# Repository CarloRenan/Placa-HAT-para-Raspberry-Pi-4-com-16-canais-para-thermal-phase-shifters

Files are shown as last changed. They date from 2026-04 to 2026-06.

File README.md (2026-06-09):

# Placa-HAT-para-Raspberry-Pi-4-com-16-canais-para-thermal-phase-shifters

# Raspberry Pi 4 Photonic HAT Controller

Este repositório contém a documentação, esquemáticos e o software de controle para um HAT customizado de sinais mistos projetado para a Raspberry Pi 4. O sistema é focado no acionamento de matrizes fotônicas e condicionamento de sinais analógicos de alta precisão.

## 🧠 Arquitetura de Hardware

A rede de distribuição de energia e controle foi rigorosamente dimensionada para garantir integridade de sinal:
* **Conversão de Energia Principal:** Utiliza o conversor buck síncrono AP63205WU-7, reduzindo a tensão de entrada para um barramento regulado de 5V com capacidade de 2A.
* **Regulação Secundária (LDO):** Um AP2112K-3.3TRG1 fornece uma rede isolada de 3,3V dedicada aos circuitos digitais e analógicos sensíveis.
* **Conversão Digital-Analógica (DAC):** Implementada através do AD5391 (matriz multicanal), orquestrando a geração precisa dos sinais a partir da rede filtrada de 3,3V.
* **Condicionamento Analógico:** Matriz em cascata utilizando 4 CIs TLV2464 (totalizando 16 canais de amplificadores operacionais *rail-to-rail*), alimentados diretamente pelo barramento robusto de 5V.

## 💻 Software de Controle

Localizado na pasta `/src`, o script Python (`photonic_controller.py`) estabelece uma abstração sistêmica da placa. 
* Comunicação em altíssima velocidade (15 MHz) via barramento SPI dedicado (SPI0) para o DAC AD5391.
* Monitoramento autônomo via thread secundária para ler a transposição diferencial dos sensores INA180A2 (SPI1).
* Gatilhos emergenciais de contenção térmica via pinagem GPIO (Clear assíncrono).

## 📂 Estrutura do Repositório

* `/Projeto_DAC_Raspberry`: Arquivos fonte da PCB.
* `/docs`: Relatórios de viabilidade eletrotérmica e esquemáticos da placa.
* `/src`: Driver e interface de linha de comando em Python.



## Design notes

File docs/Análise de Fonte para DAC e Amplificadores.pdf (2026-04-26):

# Análise da tensão e corrente suficiente para alimentar o circuito

## Geração de Energia (Capacidade da Fonte)

- Conversor Buck (AP63205WU-7): Gera o barramento principal de 5 V. Suporta uma corrente máxima de saída de 2 A (2000 mA).
- Regulador LDO (AP2112K-3.3TRG1): Reduz os 5 V para gerar os barramentos de 3,3
V. Suporta uma corrente de saída máxima de 600 mA.

## Cálculo de Demanda do DAC (AD5391)

O DAC de 16 canais é alimentado em seus pinos analógicos e digitais pela tensão de 3,3 V proveniente do LDO.
- Corrente Analógica Máxima ($AI_{DD}$): 16 canais × 0,475 mA = 7,6 mA (com Boost ativado).
- Corrente Digital Máxima ($DI_{DD}$): O núcleo digital consome até 1,0 mA.
- Demanda Total do DAC (LDO 3,3 V): 7,6 mA + 1,0 mA = 8,6 mA.

## Cálculo de Demanda dos Amplificadores Operacionais (TLV2464)

A matriz de condicionamento utiliza 4 CIs TLV2464 (4 canais cada), totalizando 16 canais, alimentados diretamente pelo barramento de 5 V.
1. Demanda Quiescente (Base): 16 canais × 0,55 mA = 8,8 mA.
2. Demanda Máxima (Pior Caso/Curto-Circuito): 16 canais × 80 mA = 1280 mA.

## Demanda Global no Conversor Principal de 5 V

Todo o circuito (LDO + OPs) retira energia da via principal de 5 V.
- Cenário Base (Quiescente Total): 8,6 mA (DAC) + 8,8 mA (OPs) = 17,4 mA.
- Cenário Extremo (Pior Caso): 8,6 mA (DAC) + 1280 mA (OPs) = 1288,6 mA.
Como o conversor suporta até 2000 mA, a demanda máxima (1288,6 mA) representa aproximadamente 64% da capacidade total, garantindo uma margem de segurança adequada mesmo em situações de falha.

## Tabela Resumo de Consumo

Componente/Cálculo | Corrente Requerida | Limite da Fonte
DAC AD5391 (Via LDO 3.3V) | 8,6 mA | 600 mA (AP2112K)
Amp Op TLV2464 (Quiescente) | 8,8 mA | 2000 mA (AP63205)
Amp Op TLV2464 (Curto-circuito) | 1280 mA | 2000 mA (AP63205)
Consumo Global (Estado Passivo) | 17,4 mA | 2000 mA (AP63205)
Consumo Global (Pior Cenário) | 1288,6 mA | 2000 mA (AP63205)

## 1. Fundamentos da Arquitetura de Potência e Diretrizes de Sinal Misto

O projeto de arquiteturas de hardware de sinal misto de alta precisão e densidade exige um escrutínio rigoroso da rede de distribuição de energia. A tese central deste relatório analítico concentra-se em avaliar detalhadamente se a topologia de conversão de energia designada possui as características elétricas — especificamente os parâmetros de regulação de tensão e a capacidade máxima de fornecimento de corrente — para alimentar adequadamente uma matriz multicanal de conversores digital-analógico (DAC) em cascata com amplificadores operacionais de saída rail-to-rail. A questão central a ser respondida é se o conversor buck primário fornece tensão e corrente suficientes para o correto funcionamento do DAC e dos amplificadores operacionais documentados nos esquemáticos do projeto.

O sistema em questão depende do conversor buck síncrono AP63205WU-7 como o estágio primário de geração de energia, reduzindo a tensão de um barramento de entrada não regulado para um plano regulado de 5 V.

1 A partir deste barramento principal, a energia é distribuída em duas frentes distintas. Primeiro, o plano de 5 V alimenta diretamente uma matriz de amplificadores operacionais TLV2464, que são utilizados para o condicionamento e a entrega de potência analógica para as cargas externas.

3 Em segundo lugar, a tensão de 5 V atua como entrada para um regulador linear de baixa queda de tensão (LDO) AP2112K-3.3TRG1, cuja função é reduzir essa tensão para gerar barramentos isolados de 3,3 V.

4 Estes barramentos de 3,3 V são dedicados à alimentação do conversor digital-analógico AD5391, que orquestra a geração de precisão dos sinais analógicos a serem posteriormente buferizados pelos amplificadores.

3

Para fornecer uma resposta definitiva sobre a viabilidade e robustez do conversor buck primário em sustentar as cargas analógicas e digitais em cascata, é necessário conduzir uma análise eletrotérmica e elétrica multidisciplinar. As seções seguintes deste documento desconstruirão as capacidades operacionais do conversor AP63205WU-7, avaliarão os gargalos de dissipação de energia no LDO AP2112K, calcularão os orçamentos de corrente estática e dinâmica para o DAC AD5391 e para a matriz de amplificadores TLV2464, e abordarão fenômenos de integridade de energia de segunda ordem, como propagação de ruído de comutação, sequenciamento de alimentação e resposta a transientes de carga.

## 2. Geração de Potência Primária: O Conversor Buck Síncrono AP63205WU-7

O estágio de entrada de energia dita a estabilidade de todos os subsistemas a jusante. A topologia de conversão principal é construída em torno do AP63205WU-7, um regulador de tensão chaveado síncrono (buck) altamente integrado, encapsulado em um invólucro TSOT-26 de dimensões reduzidas.

1

### 2.1 Topologia Arquitetural e Características de Comutação

A arquitetura do AP63205WU-7 é definida por sua capacidade de aceitar uma ampla faixa de tensão de entrada, operando nominalmente desde 3,8 V até um limite máximo de 32 V.

1 Esta amplitude confere ao circuito uma enorme flexibilidade, permitindo que o sistema seja alimentado por barramentos industriais de 12 V ou 24 V, ou até mesmo baterias automotivas, mantendo a estabilidade na geração de uma saída fixa de 5 V.

6

O dispositivo é caracterizado pela integração monolítica de ambos os transistores de efeito de campo (MOSFETs) de potência no próprio substrato de silício. O MOSFET de alta

(high-side) apresenta uma resistência de condução (estado ligado ou | ) de 125
m$\Omega$, enquanto o MOSFET síncrono de baixa (low-side) utiliza uma topologia otimizada
com um | de apenas 68 m$\Omega$.

1 A retificação síncrona inerente ao AP63205 elimina a necessidade de um diodo Schottky de roda livre externo, o que melhora significativamente a eficiência volumétrica da placa de circuito impresso (PCI) e reduz drasticamente as perdas de comutação e condução.

Para um conversor buck operando no modo de condução contínua (CCM), as perdas de

condução em regime estacionário ( | ) dentro do invólucro podem ser matematicamente
aproximadas pelo ciclo de trabalho (duty cycle, | ) e pelas resistências térmicas dos
interruptores internos. O ciclo de trabalho é primariamente uma função da razão entre a tensão
de saída e a tensão de entrada ( | ). Assumindo um cenário de operação com

uma entrada nominal de 12 V para produzir a saída de 5 V, o ciclo de trabalho é de aproximadamente 41,6%.

A especificação mais crítica para a validação deste projeto é que o conversor AP63205WU-7 é classificado para fornecer uma corrente de saída contínua máxima de 2 A.

1
Operando em sua corrente máxima de 2 A, as perdas de condução estritas nos MOSFETs internos resultariam em menos de 400 mW de dissipação de calor. Esta alta eficiência térmica permite que o dispositivo TSOT-26 suporte a carga de 2 A de maneira sustentável, desde que as condições da placa e a temperatura ambiente não ultrapassem o limite operacional extremo de 85 °C e a temperatura máxima de junção de 160 °C.

2

### 2.2 Malha de Controle e Mitigação de Interferência Eletromagnética

A qualidade da energia fornecida a circuitos de sinal misto, como o DAC AD5391 e os amplificadores operacionais TLV2464, é tão importante quanto a quantidade de corrente disponível. A malha de controle do AP63205WU-7 emprega o modo de controle de corrente de pico (Peak Current Mode Control), acoplado a uma rede de compensação integrada internamente.

1 O controle de modo de corrente de pico fornece limitação de corrente ciclo a ciclo inerente e excelente resposta a transientes de linha, o que é altamente benéfico quando se alimentam CIs analógicos sensíveis a ruídos. A compensação interna minimiza a contagem de componentes passivos externos, acelerando a estabilização da malha durante transientes de carga abruptos — como aqueles encontrados quando uma matriz multicanal de amplificadores operacionais impulsiona subitamente cargas capacitivas ou resistivas.

A frequência de comutação do AP63205WU-7 é fixada em 1,1 MHz.

2 Operar em uma
frequência superior a 1 MHz permite a utilização de indutores de baixo perfil e capacitores cerâmicos de saída com baixa resistência em série equivalente (ESR), o que suprime efetivamente a ondulação (ripple) da tensão de saída. A análise esquemática indica a presença
de um indutor de 4,7 | H associado a dois capacitores de saída de 22 | F em paralelo, uma
configuração clássica para minimizar o ripple de tensão em conversores de 1,1 MHz.

Ainda mais relevante para aplicações analógicas é o fato de que o AP63205WU-7 integra uma função de Espalhamento de Espectro de Frequência (Frequency Spread Spectrum

- FSS) que introduz um jitter deliberado de | 6% na frequência de comutação.
| | 1 Ao modular
continuamente a frequência fundamental de comutação entre aproximadamente 1,034 MHz e 1,166 MHz, a energia eletromagnética emitida é impedida de se concentrar em uma única ressonância fundamental. Esta capacidade de FSS reduz drasticamente os picos de interferência eletromagnética (EMI), diminuindo a probabilidade de que emissões irradiadas ou conduzidas se acoplem às entradas de alta impedância dos amplificadores operacionais TLV2464 ou aos pinos de referência de precisão do DAC AD5391.

### 2.3 Estado Operacional Quiescente e Eficiência Dinâmica

Sob condições de ausência de carga (no-load), o AP63205 exibe uma corrente

quiescente ( | ) ultrabaixa de apenas 22 | A.

1 Embora a corrente quiescente seja uma métrica crucial para arquiteturas operadas por bateria, em sistemas industriais de alta densidade que impulsionam buffers analógicos contínuos, o carregamento dinâmico dominará inteiramente os cálculos de potência. A capacidade central do regulador de fornecer 5 V e sustentar picos de 2 A forma a base sólida a partir da qual as cargas subsequentes extrairão energia.

## 3. Regulação Secundária de Tensão: O LDO AP2112K-3.3TRG1

Embora o trilho de 5 V gerado pelo conversor buck primário forneça a potência maciça para o estágio de amplificação, componentes digitais e de sinal misto de menor geometria frequentemente exigem tensões operacionais menores. A análise do esquemático revela que o barramento de saída +5V_Ext alimenta um regulador linear AP2112K-3.3TRG1.

4 A função
deste componente é atuar como um estágio redutor linear (Low-Dropout - LDO) para gerar o plano de 3,3 V necessário para o conversor digital-analógico e para a interface de comunicação.

### 3.1 Queda de Tensão (Dropout) e Limites de Corrente

O AP2112K-3.3TRG1 é um regulador linear com saída fixa de 3,3 V e capacidade para fornecer uma corrente de saída contínua de até 600 mA.

4 O dispositivo opera com uma tensão de dropout (diferencial mínimo entre entrada e saída) típica de 250 mV, atingindo um pior cenário máximo de 400 mV quando operado na sua carga limite de 600 mA.

4

Como o conversor buck primário alimenta o LDO de forma contínua com uma tensão regulada de 5,0 V, o diferencial de tensão (headroom) através do LDO é de exatos 1,7 V (

). Este delta de 1,7 V é substancialmente mais alto que o limite de dropout de 400 mV estipulado pelo fabricante. Isso assegura categoricamente que o LDO jamais entrará na região de dropout ou sub-regulação, mantendo uma regulação de carga imaculada, especificada em 0,2 %/A, sob todas as condições transientes e de estado estacionário concebíveis nesta topologia.

9 A tensão de entrada nominal também está bem abaixo da tensão máxima absoluta suportada pelo AP2112K, que é de 6,0 V.

4

### 3.2 Análise de Gargalo Térmico e Dissipação do LDO

Embora as especificações elétricas do LDO permitam um fluxo de corrente de 600 mA

4
,
a física térmica de semicondutores impõe um limite muito mais restritivo ao AP2112K-3.3 quando este é operado a partir de uma fonte de 5 V. Em qualquer regulador linear, a potência

dissipada internamente ( ) é manifestada como calor e é igual ao produto da corrente de carga pelo diferencial de tensão entre a entrada e a saída:

Se o sistema de fato exigisse a corrente máxima nominal de 600 mA deste barramento de 3,3 V, a dissipação de energia interna no LDO seria de estratosféricos 1,02 Watts. O encapsulamento SOT-25 (também conhecido como SOT-23-5), em que este LDO é fornecido,

exibe uma resistência térmica entre a junção e o ambiente ( ) de 184 °C/W quando montado em uma placa de circuito impresso padrão sem dissipadores de calor dedicados de grande área.

11 Operar a 1,02 W de dissipação resultaria em um aumento fenomenal da temperatura de junção:

Somar esse aumento de temperatura a um ambiente industrial nominal de 25 °C

resultaria em uma temperatura de junção ( ) de 212 °C. Tal temperatura excede drasticamente a proteção de desligamento térmico incorporada no chip (Thermal Shutdown), que é ativada quando a junção atinge 160 °C

11 | , e também viola a temperatura de operação
máxima recomendada de 85 °C.

10

A conclusão fundamental da análise do regulador LDO é que, embora possua uma classificação elétrica de 600 mA, o gargalo térmico derivado da queda de 5 V para 3,3 V limita a corrente contínua sustentável a valores significativamente inferiores (idealmente abaixo de 200 mA para manter a integridade térmica de longo prazo). Felizmente, como será demonstrado na seção dedicada ao DAC AD5391, a corrente demandada pelo estágio de sinal misto em 3,3 V é de apenas uma fração desta capacidade, confirmando a robustez da escolha arquitetural sob condições reais de carga.

### 3.3 Rejeição de Ruído e Filtragem de Barramento Split

O AP2112K fornece uma Razão de Rejeição de Fonte de Alimentação (PSRR) de 65 dB na faixa de frequência de 100 Hz a 1 kHz, garantindo que ruídos de baixa frequência introduzidos na linha de 5 V sejam barrados da saída de 3,3 V.

| 4 No entanto, a eficiência de
rejeição decai em frequências mais altas. Para combater a interferência de alta frequência residual (como o ripple de 1,1 MHz proveniente do conversor buck), a análise esquemática revela um refinamento de projeto notável: a divisão do plano de 3,3 V.

O LDO gera a rede primária +3.3V_Ext, que é encarregada de alimentar as porções digitais barulhentas do circuito (como o núcleo digital do DAC). A partir desta rede, um filtro do tipo passa-baixa, composto por um indutor bead de ferrite (FB1, especificado como BLM18KG601SN1D) e capacitores de desvio cerâmicos, é implementado para gerar a rede +3.3V_Analog. Esta rede +3.3V_Analog isolada galvanicamente e filtrada de ruídos de alta frequência é então empregada para alimentar a matriz analógica de alta precisão do DAC, atestando o alto rigor aplicado na busca pela integridade do sinal misto.

## 4. Análise de Carga do Conversor Digital-Analógico: Família AD5391

Com as fundações da fonte de alimentação quantificadas e os comportamentos de tensão e térmicos delineados, o próximo passo na determinação da suficiência da corrente e tensão envolve a dissecção das cargas anexadas. A primeira carga substancial no fluxo de sinal é a matriz de conversores digital-analógico (DAC). O esquemático identifica a presença de um DAC de 16 canais. Os dados de pesquisa indicam que a família engloba o AD5390 (14 bits), AD5391 (12 bits) e AD5392 (8 canais, 14 bits).

3 A análise focará no AD5391 como referência para os modelos de 16 canais.

### 4.1 Identificação da Variante de Tensão Operacional

Os DACs desta família, particularmente o AD5391, são fisicamente divididos em duas subvariantes que ditam os requisitos operacionais de tensão de seu projeto interno: a versão

"-5", cujas especificações exigem um barramento de alimentação analógica ( | ) situado
entre 4,5 V e 5,5 V, e a versão "-3", projetada para operar em sistemas de baixa tensão com
um | compreendido entre 2,7 V e 3,6 V.

3 Em ambas as variantes, o pino de alimentação

do núcleo lógico e da interface digital ( ) aceita tensões numa ampla gama, estendendo-se desde 2,7 V até 5,5 V, garantindo a interoperabilidade com sistemas microcontroladores ou FPGAs independentemente das tensões do estágio analógico.

3

Uma interpretação errônea comum seria assumir que o DAC é alimentado diretamente pelo regulador buck principal de 5 V, o que exigiria a variante AD5391-5. No entanto, uma escrutinação atenta do diagrama esquemático fornecido refuta decisivamente essa suposição. Os pinos de alimentação analógica do DAC (AVDD 1 e AVDD 2) não estão conectados ao barramento +5V_Ext. Ao invés disso, eles são mapeados indubitavelmente para a rede filtrada +3.3V_Analog, proveniente do LDO AP2112K. Adicionalmente, a alimentação lógica do DAC, o pino DVDD, está conectado ao barramento digital limpo +3.3V_Ext, também proveniente do LDO.

Essa implementação baseada no LDO estabelece irrefutavelmente que a variante de dispositivo empregada ou necessária para esta placa é o AD5391-3 (ou as correspondentes

AD5390-3 / AD5392-3). Com os barramentos | e | ancorados ambos em 3,3 V, a
arquitetura da alimentação atende de forma perfeita e centralizada à recomendação do fabricante para o AD5391-3, cuja faixa operacional permitida de 2,7 V a 3,6 V engloba o valor de 3,3 V com ampla margem de segurança contra flutuações, respondendo positivamente à questão de que a tensão disponibilizada é suficiente e adequada.
| | 3

### 4.2 Restrições de Sequenciamento de Inicialização (Power-On Reset)

Projetar sistemas de sinal misto vai além do simples cálculo de correntes; as dinâmicas de tempo são cruciais para prevenir travamentos catastróficos em nível de silício (latch-up). A documentação técnica do AD5391 estipula um protocolo severo e compulsório relativo ao

sequenciamento da aplicação das tensões de alimentação nos pinos | e | . Para
assegurar a operação correta do circuito de reinicialização por ligação (Power-On Reset - POR)
e evitar estados indeterminados, o projetista deve garantir que o | seja aplicado
simultaneamente com o | , ou que o | antecipe o surgimento do | .

3

Adicionalmente, se houver um atraso na subida de tensão, o | deve estabilizar-se em
até, no máximo, 10 milissegundos após o estabelecimento do | .

3 Se o suprimento
analógico subir antes do suprimento digital, ou ultrapassar substancialmente essa janela temporal de tolerância, a rede interna do DAC pode incorrer em polarização parasita através de diodos internos de proteção contra descarga eletrostática (ESD), acionando o indesejado fenômeno de SCR latch-up que eleva subitamente o consumo de corrente do dispositivo e inutiliza a operação digital do chip.

Na presente arquitetura, o uso inteligente da rede de 3,3 V demonstra robustez notável nesse

quesito. Ambos os pinos | e | derivam suas fontes originais de energia da mesma
saída fundamental do LDO AP2112K-3.3, e assim as subidas em suas respectivas redes (+3.3V_Analog e +3.3V_Ext) ocorrem de maneira harmonicamente atrelada. As diferenças temporais na taxa de subida de tensão entre eles são causadas meramente pelos atrasos intrínsecos impostos pela constante de tempo RC gerada pelo indutor bead de ferrite e pelos capacitores locais de desvio no plano analógico. Essa modulação temporal parasitária reside tipicamente na ordem de dezenas a centenas de microssegundos, o que é inteiramente compatível e inofensivo sob a janela limitante rigorosa de 10 ms definida pelo fabricante.

3 Este
aspecto sela a viabilidade da topologia.

### 4.3 Orçamento Computacional do Consumo Quiescente e Dinâmico do DAC

A quantificação final acerca do consumo se concentra nas demandas elétricas de núcleo e acionamento estático. O consumo intrínseco de corrente deste DAC construído em processo semicondutor CMOS é minúsculo, mas ainda assim vital para agregar ao orçamento da fonte buck primaria, haja vista que toda a energia do LDO se origina do buck de 5 V.

A drenagem de corrente analógica contínua absorvida pelo pino | (definida como

) na variante -3 obedece à parametrização do registrador de controle interno que modula o recurso de ganho de resposta dinâmica (Slew Rate Boost).

3 A arquitetura dos
amplificadores de buffer de tensão de saída no chip é otimizada para o balanceamento entre velocidade e consumo.

- Sem o Impulso Dinâmico (Boost Mode Off): Por padrão após a inicialização, a malha aceleradora está desativada, configurando o tempo de assentamento (settling time) para
cerca de 8 | s e o slew rate típico em 1,5 V/ s. Nesse regime de economia, o consumo
nominal | por canal repousa em aproximadamente 0,25 mA, com um máximo
estatístico tolerável listado em 0,375 mA sob extremas variações de temperatura industrial (-40 °C a 85 °C).

3
- Com o Impulso Dinâmico (Boost Mode On): Quando um controle de sistema de mais alta velocidade exige transições abruptas, a configuração do registrador CR11 ativa o Boost Mode.

3 Este modo otimiza as correntes de polarização e aumenta o slew rate dos

canais para cerca de 2,5 V/ s. Em troca deste incremento performático, o teto da

corrente consumida | é impelido a um máximo de 0,475 mA por canal.

3

Para propósitos de assegurar as margens estruturais do regulador de tensão, o pior cenário (Boost Mode On operando a alta temperatura com todos os canais acionados) deve ser projetado. Com 16 canais ativos de maneira simultânea e absorvendo 0,475 mA de corrente do

de 3,3 V, a demanda global do núcleo analógico do chip ( | ) cristaliza-se
em:
O núcleo digital e as portas lógicas da interface SPI absorvem corrente adicional ( | ) por
meio do pino | . Quando a interface de comunicação é operada com sinais estáticos ou
em baixas frequências transicionais, a corrente | é insignificante. No entanto, quando
sujeita à comutação de alta velocidade (até o limite nominal especificado e assumindo
transições com níveis corretos em pinos CMOS), a corrente | alcança o teto máximo de
1,0 mA.

3

Integrando ambos os parâmetros computados ( | mais | ), conclui-se que o
requisito máximo teórico contínuo imposto por toda a operação do bloco DAC de 16 canais resume-se a escassos 8,6 mA. A capacidade do LDO AP2112K é de 600 mA.

4 Portanto, a
carga imposta pelo DAC perfaz uma fração microscópica (menos de 1,5%) da capacidade disponível em corrente secundária, corroborando de maneira explícita que as especificações estão mais do que supridas para este dispositivo em tela. Além do consumo intrínseco, os
saídas do DAC ( | a | ) não direcionam cargas resistivas de baixa impedância
significativas, pois seus sinais penetram diretamente na entrada não-inversora de altíssima impedância de porta dos amplificadores operacionais TLV2464 dispostos no estágio vizinho.

5. | Exigências | Eletrotérmicas | da | Matriz | de

## Amplificadores Operacionais: Família TLV2464

Conectados em topologia de cascata subsequente aos canais do DAC, os sinais analógicos necessitam ser submetidos a buffer, ganhos e condicionamento capaz de prover força motriz de corrente para as eventuais redes externas ao produto final. A arquitetura emprega a matriz do TLV2464, um pacote cuádruplo contendo amplificadores operacionais otimizados para baixo consumo de energia, exibindo um regime irrestrito de excursão de sinal tanto nas entradas quanto nas saídas, coloquialmente denominado rail-to-rail.

| | | | 3

A representação esquemática atesta a necessidade de lidar com 16 vias paralelas. Deste modo, são demandados e implantados quatro chips integrados individuais TLV2464CDR (cada qual contendo 4 amplificadores independentes).

| | 3

### 5.1 Restrições e Adequações na Tensão de Alimentação

O TLV2464 e os membros remanescentes de sua respectiva família ostentam

compatibilidade e flexibilidade superiores em relação a tensões de alimentação ( ). Segundo o guia de seleção e as classificações recomendadas pelo fabricante de silício, a tensão singular de alimentação do circuito deve incidir sobre a faixa permitida de 2,7 V a 6,0 V.

| | | | | 3

Ao avaliar as interconexões mostradas, observa-se que os pinos de polarização de alimentação (VDD+) de toda a fileira de amplificadores TLV2464 estão umbilicalmente atados de forma sólida ao barramento original +5V_Ext, derivado com rigor sem intermediários da conversão gerada pelo regulador buck principal AP63205WU-7.

| | 3
- Verificação: Uma alimentação de 5,0 V não apenas satisfaz a janela preconizada (2,7 V -6,0 V), como também fornece um patamar otimizado de dinâmica e amplitude de sinal. Ao ser nutrido por 5 V, as habilidades de excursão de sinal (rail-to-rail) garantem que a saída

possuirá um nível alto ( ) de 4,8 V (mínimo de 4,7 V) quando operando sob fornecimento de carga razoável de 10 mA. Igualmente, no dreno de corrente sob a

mesma magnitude de 10 mA, o nível baixo garantido ( ) pode atingir um teto de no máximo 0,3 V (tipicamente 0,2 V).

3 Como o próprio AD5391 operando a 3,3 V enviará

apenas os limites contidos de sua variação ( | V), a amplitude máxima a ser
engolida pelas entradas não inversoras repousará perfeitamente dentro da aceitação linear em modo comum (Common-Mode Input Voltage Range) dos amplificadores

energizados em 5 V, os quais possuem o privilégio de rastrear perfeitamente do marco

V até a própria tensão do barramento ( de 5 V).

3 Esta particularidade sela incontestavelmente a questão técnica quanto à suficiência das margens de tensão.

### 5.2 Orçamento de Corrente Quiescente (Demanda Passiva)

A balança que mensura o desempenho do TLV2464 versus sua sede elétrica revela notável compromisso com a economia. Os atributos inerentes ao ganho e à velocidade desta topologia CMOS não sacrificam em demasia a eficiência. Com um respeitável Produto Ganho-Banda (GBW) estipulado em 6,4 MHz e um razoável tempo de assentamento associado

a uma variação de fase de tensão (Slew Rate) delineado em 1,6 V/ s, cada canal no encapsulamento puxa para seu sustento interno uma pequena corrente de suprimento passiva

( | ) listada em 550 | A sob todas as faixas de trabalho industrial (aumento pequeno
frente ao patamar base estrito de 500 | A aferido em condição de temperatura ambiente e sem
estresse contíguo de transientes).
| | 3

Para estimar a porção puramente quiescente de toda essa formidável matriz de condicionamento na placa, consolidamos os quatro encapsulamentos de 4 vias (perfazendo 16 componentes ativos):

O valor computado de 8,8 mA define a barreira mais baixa de escoamento energético em corrente contínua que passará compulsoriamente, dia a dia e minuto a minuto, pelos filtros do barramento de 5 V provido pelo conversor buck. Evidentemente, esta cifra pálida desaparece frente à pujante magnitude de 2.000 mA do equipamento formador da energia, certificando sobra absurda na capacidade estática.

### 5.3 O Teto Dinâmico, Imposição de Cargas Extremas e Limitações Físicas do Empacotamento

Diferentemente do comportamento dócil e estável do conversor de sinais DAC, cujos elétrons desvanecem imperceptivelmente em resistências elevadas no domínio mega e giga ohm, o cenário modifica-se sensivelmente nas vias terminais do equipamento de controle, representadas pelos TLV2464. Estes portais fazem a mediação dos sinais gerados digitalmente contra a realidade mecânica e tangível, traduzida por longas linhas de transceptores, cabos coaxiais pesados, cargas térmicas ou transdutores mecânicos complexos. A integridade da corroboração da viabilidade exige o conhecimento das correntes induzidas pela carga dinâmica, independentemente da taxa passiva estática.

De acordo com as averiguações em ficha técnica, o TLV2464 fornece alta capacidade motriz impulsionadora. Em episódios nos quais for compelido a agir sob demanda ou erro (curto-circuito ou similar), o componente está homologado a entregar até a expressiva corrente

de curto-circuito ( | ) de | 80 mA (sendo 50 mA testado rigidamente e garantido
estatisticamente e 80 mA na distribuição típica da engenharia, assumida aqui como limite extremo no sentido de esgotamento total para teste das fontes).

3

Por premissa avaliativa fundamental de estresse (stress-testing paper model), caso se imponha a situação limite onde a falha nos sistemas externos ou comandos erráticos cause que simultaneamente, inexoravelmente, todos os 16 canais interconectados na matriz da placa tentem despachar 80 mA continuamente para o exterior, a corrente absoluta forçada contra a fonte ascenderia para:

Com base no pilar mestre das especificações prementes de fonte documentadas na seção 2.1

1
, as provisões estabelecem o limitante contínuo em 2,0 A. Dessa maneira, mesmo neste flagrante e colossal absurdo estressor imaginário de 1,28 Amperes dreno por parte dos estágios de saída, a capacidade vital de 2,0 Amperes do equipamento fonte AP63205 suportaria o esforço contínuo da demanda, guardando ainda formidável reserva excedente em trono de 720 miliamperes para compensação de perdas parasitárias de cabos ou necessidades de surtos microscópicos residuais. Fica assim matematicamente exaurida e devidamente resolvida a inquirição primária elaborada pelo consulente de forma afirmativa: Sim, há corrente elétrica global abundante.

### 5.3.1 O Abismo Térmico e o Verdadeiro Limitante do Sistema

No entanto, o relato estrito das capacidades dos transistores do conversor principal de silício dissimula as restrições práticas encontradas nas cápsulas encapsuladoras de plástico. Um exame analítico eletrotérmico dos próprios circuitos integrados amplificadores é mandatório para compreender as limitações práticas operacionais que, antes de drenarem por completo o reservatório do conversor, ceifariam o desempenho do dispositivo.

Em um contexto operacional adverso, postulemos o canal do op-amp sendo constrangido a drenar 80 mA a partir dos limitados reservatórios internos para uma eventual falha limitadora posicionada de modo a requerer tensão pela metade. Com alimentação total de 5 V, as perdas localizadas inerentes resultantes dessa queda seriam equivalentes ao diferencial das tensões contra a passagem da corrente.

Assumindo queda abrupta de 2,5 V internamente aos domínios comutadores para sustentar os 80 mA, a potência em watts despejada apenas como aquecimento reativo (

) em único circuito somaria 200 mW. Dentro da embalagem unificadora TLV2464D, onde residem concomitantemente quatro vias de atuação, essa perda multiplicada perfazeria

estrepitosos 800 mW ( W).

A tabela explícita de "Classificação de Dissipação" (Dissipation Rating Table) associada ao empacotamento pequeno tipo contorno de montagem em superfície (D - Small Outline 14 Pinos), fornece as amarras ineludíveis para sobrevivência em silício: A resistência ao

transbordo térmico ( equivalente) foi laboratorialmente cimentada em pesados 122,6

°C/W.

3

A potência de 800 mW causaria gradiente na junção contra o invólucro ( ) calculado por:

Em cenário confortável e temperado de operação interior industrial fixada estritamente aos 25 °C, o aquecimento provocado internamente conduziria os dados microscópicos imediatamente à elevação nominal para 123 °C.

3 O datasheet aponta que a máxima qualificação da temperatura contínua no núcleo central da operação permitida sem cataclismos

de tempo e sem fadiga estrutural ( | máximo e variação | expandido) encerra-se
perigosamente e ironicamente também perto dos idênticos 125 °C.
| | 3 Qualquer desvio
rudimentar superior de aquecimento externo da cabine faria com que a junção entrasse em zona perigosa ou mortífera.

Assim, com incontestável evidência físico-térmica, provamos o grande paradoxo do dimensionamento de sinal misto para controle industrial: A limitação da extração elétrica final imposta ao cliente jamais repousará nas limitações de fornecimento impostas pelo regulador Buck síncrono de 5 V. Muito tempo antes de que os potentes MOSFETs do conversor AP63205 sequer suem ao extrair seus maciços 2 Amperes, as minúsculas pastilhas que acondicionam e embalam o silício retificado dos TLV2464 entrarão em picos sufocantes por superaquecimento derivado do atrito eletrotérmico caso se submetam as saídas contínuas a frações massivas da capacidade de carga teórica da fonte. O regulador é uma usina amplamente dimensionada; a contenção mora inteiramente em quão bem a engenharia de arrefecimento nos chips analógicos finais for disposta.

Para ajudar no diagnóstico, os projetistas frequentemente introduzem resistências extrínsecas no circuito impresso, limitadores que servem de alívio e contorno do problema.

Constata-se efetivamente na topologia da imagem que os caminhos de saída ( | ou Main
AMP OPx IN) antes de finalizarem nos soquetes de engate, sofrem intervenções intencionais. Fichas de policarbonato com coeficiente positivo sensível de aquecimento — no caso referenciado no diagrama esquemático como MF-PSMF010X-2, os chamados fusíveis PTC (Positive Temperature Coefficient) — e monitores de resistência de derivação paralela baseados em CIs dedicados ao sensoriamento apurado de vias, do naipe INA180A2, efetuam o controle perene das malhas.

3 Tais componentes, ao lado da barreira do LDO AP2112, apenas consagram os contornos periféricos, cujo consumo insignificante em correntes do porte dos micro-amperes desaparece por completo sob as sobras colossais do sistema geral de energia.

| | 4

## 6. Integração Final e Orçamento Global de Requisitos de Potência

Para sintetizar o conhecimento das longas corroborações das seções transcorridas e cimentar as avaliações numa premissa técnica e legível para consultas dos pares atuantes no projeto, a matriz consolidada de orçamentos se faz primordial.

As tabelas de apuração listam não apenas o estado de base ou nominal operacional (fase inativa), mas projetam o avanço sob as piores hipóteses prementes de estresse das vias. Os cenários se baseiam em consumos passivos nominais da fonte principal AP63205 e na regulação passiva do AP2112 LDO operando os consumos dinâmicos dos CIs. A matriz assume os dados mais restritivos listados nas análises anteriores e nos trechos das folhas de dados pesquisados, não subestimando nenhuma corrente.

A tabela ilustra de forma concisa e definitiva as compatibilidades entre a geração de 2 A imposta pelo AP63205 versus a compilação máxima de todos os agentes atrelados e pendurados elétrica e parasitariamente abaixo desta linha mestre principal.

Subsistema/Comp onente Avaliado | Corrente Estática Máxima (Standby) | Corrente Nominal Carga (10 mA / canal operando) | Limite Extremo Hipotético Máximo de Saída Curto (80 mA/ch)
Conversor Buck AP63205 (Inerente) | 0,022 mA | 0,022 mA | 0,022 mA
Regulador LDO AP2112K (Inerente) | 0,055 mA | 0,055 mA | 0,055 mA
Matriz DAC AD5391 (Rede ) | 7,600 mA | 7,600 mA | 7,600 mA
Matriz DAC AD5391 (Rede ) | 1,000 mA | 1,000 mA | 1,000 mA
Matriz de Amp Op TLV2464 (Base) | 8,800 mA | 8,800 mA | 8,800 mA
Total Corrente Imposta Via Saída | 0,000 mA | 160,000 mA | 1280,000 mA

(Cargas Amp Op)

Consumo Total Consolidado do Projeto | 17,477 mA | 177,477 mA | 1297,477 mA
Capacidade Disponível do Conversor 1 | 2000,00 mA | 2000,00 mA | 2000,00 mA
Margem Total de Energia Sobressalente Global | 99,1% Excedente | 91,1% Excedente | 35,1% Excedente

A evidência contida e agrupada prova estatisticamente, com a veracidade das contas matemáticas e as especificações de datasheet dispostas nas fontes indexadas, o preceito central submetido na questão geradora deste documento. A fonte formadora (regulador buck comutada contendo saída regulada de 5 V / capacidade retentiva de 2 A) suporta as cargas pendentes do DAC e da fileira de matriz dos Operacionais (OPs) de forma folgada.

Durante os percalços do trajeto da aplicação do cenário realista (condicionamento sob níveis normais de saídas até 10 mA em cargas limitadas e sob fusíveis limitadores PTC documentados no projeto original

3
), as folgas disponíveis na matriz indicam que o conversor comutador Buck passa por uma existência inteiramente plácida possuindo 91,1% de corrente bruta aguardando inutilizada. Nem sequer com o projeto encurralado na barreira final do desastre máximo contendo quase 1,3 A drenados — ponto onde antes as matrizes já teriam derretido as suas proteções por limite térmico como fartamente atestado na seção de avaliação física da pastilha empacotada D-14 — o sistema de energia se curvaria, exibindo fortes e incólumes 35% adicionais de robustez em potência livre.

1

## 7. Considerações Avançadas: Rejeição de Ruído e Integridade do Condicionamento Analógico

Garantir os elétrons e os diferenciais nominais em níveis de consumo mediano atinge apenas as premissas triviais para que os subsistemas "acordem". Num equipamento voltado à modulação apurada de redes e correntes — na exata via onde atuam DACs contendo taxas como 12 e 14 bits (AD5391/90) e malhas analógicas fechadas em OPs — impera adicionalmente que o sistema apresente limpeza inaudível e sem resíduos nos vetores do barramento gerador.

A natureza da comutação rápida empregada pelo síncrono AP63205WU-7 insere na rede artefatos que não existem com a aplicação singela das baterias ideais antigas. Com uma comutação assente a 1,1 MHz fixos (aprimorada em variabilidade de dispersão pela modulação de 6% FSS contra harmônicas)

1
, flutuações e dentes-de-serra residuais (ripple), usualmente na casa dos 10 mV a 30 mV, vagarão perenemente impulsionados pelo barramento de 5 V.

Quando o DAC, responsável e dependente da variação mínima, se encarrega da transcrição da codificação binária em voltagem escalar, a magnitude isolada do nível de transição elétrico menor mensurável do chip AD5391 (Least Significant Bit ou LSB),

configurado nas fontes documentadas nas especificações de precisão de LSB de 1 bit de

desvio

3
, equivale à proporção absoluta associada ao nível de tensão da rede dividida por para as versões comumente atreladas ao conversor de 12 bits. Se este artefato residual em 1,1 MHz de dezenas de milivolts viajar incólume no barramento primário de energia sem bloqueio
para as entradas | de sensibilidade contida, poderia embutir contaminações maciças do
erro, ofuscando a estabilidade real das resoluções no bloco.

3

Para aplacar esse cenário em conformidade aos limites dos chips, o comportamento do esquemático na conversão inicial e divisão (do isolado 3,3 V via matriz linear reguladora e filtros indutivos) se exibe brilhante. Os 30 mV ruidosos que viajam desde a geração perdem substancial resíduo na contenção gerada pelos laços limitadores dos divisores da rede AP2112K-3.3 que atua passiva sob índices típicos listados de cerca de 65 decibéis em PSRR para patamares sônicos (degradando em frequências maiores inerentemente pelas suas chaves).

4 A limpeza final efetiva para sanar e amansar a harmônica extrema no barramento

específico do | se faz não pelo LDO per se, mas pela notória blindagem propiciada nos
elos paralelos LC elaborada por FB1 e as malhas capacitivas cerâmicas na divisão +3.3V_Analog.

No campo de análise dos amplificadores sob o plano principal impuro de 5 V, em observação às propriedades de isolação internas intrínsecas construídas na malha analógica dos próprios CIs TLV2464 perante este barramento exposto, as especificações documentais asseguram resiliência maciça.

3 É estipulado formalmente pela literatura e guias fornecidos para esta matriz uma Taxa Racionalizada de Rejeição e Intervenção de Fonte de Alimentação (KSVR ou PSRR analógico interno do estágio) estancada num típico valor limiar massivo de 85 dB contra aberrações nos pinos propulsores.

3

Com base nisto, em conjunto com as garantias plenas da blindagem filtrada (ferrite e bypass na capacitância local) que constam associados a essas matrizes, o dimensionamento elétrico passa intacto e perfeitamente ajustado pela revisão da barreira da integridade do condicionamento.

## 8. Síntese Conclusiva

Por meio da profunda análise de requisitos eletrotérmicos, da dissecção funcional comparativa dos projetos em esquemas elétricos e das folgas paramétricas consolidadas na compilação exaustiva do projeto e nos recortes da literatura técnica validada (datasheets) e cruzada, as indagações acerca da viabilidade funcional são respondidas afirmativamente sem margem para ambiguidade conceitual de nível elétrico:

A fonte propulsora em regime síncrono Buck operada pelo comutador de redução passiva AP63205 garante a irrestrita entrega e modulação na suficiência para as tensões necessárias do projeto (produzindo o barramento forte em 5 V e fornecendo as bases perfeitas atreladas aos limites ideais estipulados entre 2,7 V e 6,0 V exigidos aos amplificadores). A energia também embasa impecavelmente a contenção auxiliar redutora via LDO restrita a 3,3 V requerida em virtude das versões específicas restritivas contidas em modelos com terminação "-3" da fileira dos AD5391.

No espectro de potência absoluta transferível (amperagem estática e transiente), a geração primária listada para limites em 2.000 miliamperes é formidavelmente hiperdimensionada frente aos meros ~177 miliamperes necessários e suficientes para compor o consumo operacional esperado e condicionado pelas redes em estado prático do ambiente das cargas das interfaces analógicas anexadas, confirmando na completude irrestrita o sucesso operacional desta topologia.

Referências citadas

3. AP63205WU-7 Switching Voltage Regulator: 5V 2A TSOT26, AP63205WU-7
Regulators | Datasheet | - | Utmel, | acessado | em | abril | 26, | 2026,
https://www.utmel.com/components/ap63205wu-7-switching-voltage-regulator-5v-2a-tsot26-ap63205wu-7-regulators-datasheet?id=1164 (https://www.utmel.com/components/ap63205wu-7-switching-voltage-regulator-5v-2a-tsot26-ap63205wu-7-regulators-datasheet?id=1164)
4. AP63205WU-7 Diodes Inc. - Voltage Regulators - Switching - Distributors, Price
Comparison, and Datasheets | Octopart component search, acessado em abril 26,
2026, https://octopart.com/part/diodes-inc/AP63205WU-7
5. AP2112K-3.3TRG1 Diodes Incorporated | Voltage Regulators - DigiKey, acessado
em | | abril | | 26, | | | | 2026,
https://www.digikey.com/en/products/detail/diodes-incorporated/AP2112K-3-3TRG1/4470746 (https://www.digikey.com/en/products/detail/diodes-incorporated/AP2112K-3-3TRG1/4470746)
6. AP2112K-3.3TRG1 | DIODES | Price | In Stock | LCSC Electronics, acessado em
abril 26, 2026, https://www.lcsc.com/product-detail/C51118.html
7. AP63205WU-7 Diodes Incorporated | Mouser, acessado em abril 26, 2026,
https://www.mouser.com/ProductDetail/Diodes-Incorporated/AP63205WU-7?qs=u 16ybLDytRZtkj8PzdWCOw%3D%3D (https://www.mouser.com/ProductDetail/Diodes-Incorporated/AP63205WU-7?qs=u16ybLDytRZtkj8PzdWCOw%3D%3D)
8. AP63205WU-7 Diodes Incorporated | Voltage Regulators - DigiKey, acessado em
abril | | | 26, | | | | | 2026,
https://www.digikey.com/en/products/detail/diodes-incorporated/AP63205WU-7/98 58424 (https://www.digikey.com/en/products/detail/diodes-incorporated/AP63205WU-7/9858424)
9. AP63205WU-7 Datasheet Diodes, Download PDF - RadioLocman, acessado em
abril | | | 26, | | | | | 2026,
https://www.radiolocman.com/datasheet/data.html?di=580813&/AP63205WU-7

10. AP2112K-3.3TRG1: 600mA LDO Voltage Regulator Review & Applications -
Utmel, | acessado | em | abril | 26, | 2026,
https://www.utmel.com/components/how-diodes-incorporated-ap2112k-3-3trg1-became-a-game-changer?id=4798 (https://www.utmel.com/components/how-diodes-incorporated-ap2112k-3-3trg1-became-a-game-changer?id=4798)
11. AP2112K-3.3TRG1 Diodes Incorporated - Mouser Electronics, acessado em abril
26, | | | | | 2026,
https://www.mouser.com/ProductDetail/Diodes-Incorporated/AP2112K-3.3TRG1?qs=x6A8l6qLYDDPYHosCdzh%2FA%3D%3D (https://www.mouser.com/ProductDetail/Diodes-Incorporated/AP2112K-3.3TRG1?qs=x6A8l6qLYDDPYHosCdzh/A%3D%3D)
12. AP2112 Description Features Applications Pin Assignments - Mouser Electronics,
acessado | em | abril | 26, | 2026,
https://www.mouser.com/datasheet/2/115/AP2112-271550.pdf

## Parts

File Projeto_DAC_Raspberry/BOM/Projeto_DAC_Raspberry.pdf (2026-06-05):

Line # | Name | Description | Designator | Revision ID | Revision State | Revision Status | Quantity | Manufacturer 1 | Manufacturer Part Number 1 | Manufacturer Lifecycle 1 | Supplier 1 | Supplier Part Number 1 | Supplier Unit Price 1 | Supplier Subtotal 1
| AD5391BSTZ-3 | 16 Channel 12-Bit Single-Supply Voltage Output Digital-to-Analog Converter with Serial Interface, 3 V, -40 to +85 degC, ST-52, Pb-Free, Tray | U2 | CMP-0318-00791-2 | Released | Up to date | | 1 Analog Devices | AD5391BSTZ-3 | Volume Production | Mouser | 584-AD5391BSTZ-3 | 60.29 | 60.29
| MF-PSMF010X-2 | PTC RESET FUSE 15V 100MA 0805 | F1, F2, F3, F4, F5, F6, F7, F8, F9, F10, F11, F12, F13, F14, F15, F16 | CMP-07400-000017-1 | New From Design | Up to date | 16 Bourns | | MF-PSMF010X-2 | Volume Production | DigiKey | MF-PSMF010X-2CT-ND | 0.29 | 4.64
| SMAJ5.0A | SMAJ Transient Voltage Suppressor Diode Series, 3.5 V, -55 to 150 degC, 2-Pin SMA, RoHS, Tape and Reel | D1, D2, D3, D4, D5, D6, D7, D8, D9, D10, D11, D12, D13, D14, D15, D16 | CMP-2000-07090-1 | Released | Up to date | 16 Bourns | | SMAJ5.0A | Volume Production | Mouser | 652-SMAJ5.0A | 0.261 | 4.18
| AP2112K-3.3TRG1 | IC REG LINEAR 3.3V 600MA SOT25 | U6 | CMP-12756-000035-1 | New From Design | Up to date | | 1 Diodes Inc. | AP2112K-3.3TRG1 | Volume Production | Mouser | 621-AP2112K-3.3TRG1 | 0.57 | 0.57
| AP63205WU-7 | IC REG BUCK 5V 2A TSOT23-6 | U7 | | Not managed | | | 1 Diodes Inc. | AP63205WU-7 | Volume Production | Mouser | 621-AP63205WU-7 | 1.75 | 1.75
| DMP4065S-7 | MOSFET P-CH 40V 2.4A SOT23 | T1 | CMP-12801-000050-1 | New From Design | Up to date | | 1 Diodes Inc. | DMP4065S-7 | Volume Production | Mouser | 621-DMP4065S-7 | 0.46 | 0.46
| LTST-C170GKT | LED GREEN CLEAR SMD | D19, D20 | CMP-1674-00002-6 | New From Design | Up to date | | 2 Diodes Inc. | LTST-C170GKT | Volume Production | Mouser | 859-LTST-C170GKT | 0.1 | 0.2
| SMBJ28CAQ-13-F | TVS DIODE 28VWM 45.4VC SMB | D17 | | Not managed | | | 1 Diodes Inc. | SMBJ28CAQ-13-F | Volume Production | Mouser | 621-SMBJ28CAQ-13-F | 0.27 | 0.27
| FH28-50S-0.5SH(05) | CONN FFC BOTTOM 50POS 0.50MM R/A | J1 | CMP-11609-000009-1 | New From Design | Up to date | | 1 HIROSE ELECTRIC | FH28-50S-0.5SH(05) | Volume Production | DigiKey | HFV150DKR-ND | 2.19 | 2.19
| SG73S1ETTP1R0J | | R1, R2, R3, R4, R5, R6, R7, R8, R9, R10, R11, R12, R13, R14, R15, R16 | CMP-2002-04124-1 | Released | Up to date | 16 KOA Speer | | SG73P1ETTP1R0J | Volume Production | Mouser | 660-SG73P1ETTP1R0J | 0.042 | 0.672
| MMSZ5245B-TP | DIODE ZENER 15V 500MW SOD123 | D18 | | Not managed | | | 1 MCC | MMSZ5245B-TP | Volume Production | DigiKey | MMSZ5245B-TPMSCT-ND | 0.14 | 0.14
| 1255AY-4R7M=P3 | FIXED IND 4.7UH 4A 23 MOHM SMD | L1 | | Not managed | | | 1 Murata | 1255AY-4R7M=P3 | Volume Production | DigiKey | 490-10812-1-ND | 0.39 | 0.39
| BLM18KG601SN1D | Chip Ferrite Bead, 0603, 600Ω @ 100MHz, 0.15Ω, 25%, 1.3A | FB1 | CMP-0686-00581-3 | Released | Up to date | | 1 Murata | BLM18KG601SN1D | Volume Production | Mouser | 81-BLM18KG601SN1D | 0.1 | 0.1
| GRM31CR60J476ME19L | Chip Multilayer Ceramic Capacitors for General Purpose, 1206, 47uF, X5R, 15%, 20%, 6.3V | C41, C47 | CMP-2000-06344-2 | New From Design | Up to date | | 2 Murata | GRM31CR60J476ME19L | Volume Production | Mouser | 81-GRM426X476M6.3L | 0.5 | | 1
| GRM188R61A106ME69J | Chip Multilayer Ceramic Capacitors for General Purpose, 0603, 10uF, X5R, 15%, 20%, 10V | C6, C7, C8 | CMP-06035-033844-1 | New From Design | Up to date | | 3 Murata | GRM188R61A106ME69J | Volume Production | Mouser | 81-GRM188R61A106ME9J | 0.13 | 0.39
| Resistor 10k +/-1% 0603 100 mW | Chip Resistor, 10 KOhm, +/- 1%, 01 W, -55 to 155 degC, 0603 (1608 Metric) | R21, R23, R24, R25, R29, R31, R32, R33, R37, R39, R40, R41, R45, R47, R48, R49 | | Not managed | | 16 Panasonic | | ERJPC3B1002V | Volume Production | Mouser | 667-ERJ-PC3B1002V | 0.147 | 2.35
| 5444262 | TERM BLOCK HDR 2POS 90DEG 3.81MM | J3 | | Not managed | | | 1 Phoenix Contact | 5444262 | Volume Production | DigiKey | 277-11313-ND | 0.39 | 0.39
| 5447861 | TERM BLOCK PLUG 2POS STR 3.81MM | J2 | | Not managed | | | 1 Phoenix Contact | 5447861 | Volume Production | Mouser | 651-5447861 | 1.14 | 1.14
| CL21A226MAYNNNE | CAP CER 22UF 25V X5R 0805 | C10, C11 | | Not managed | | | 2 Samsung Electro-Mechanics | CL21A226MAYNNNE | Volume Production | Mouser | 187-CL21A226MAYNNNE | 0.26 | 0.52
| CL31A106KBHNNNE | CAP CER 10UF 50V X5R 1206 | C12 | | Not managed | | | Samsung Electro-1 Mechanics | CL31A106KBHNNNE | Volume Production | Mouser | 187-CL31A106KBHNNNE | 0.36 | 0.36
| CRGCQ0805F100K | CRGCQ 0805 100K 1% | R19 | CMP-03211-000816-1 | New From Design | Up to date | | 1 TE Connectivity | CRGCQ0805F100K | Volume Production | DigiKey | A129773CT-ND | 0.1 | 0.1
| CRGCQ0805J470R | CRGCQ0805 470Ω 0.125W ±100ppm/ °C 5% 150V | R20 | CMP-03211-002267-1 | New From Design | Up to date | | 1 TE Connectivity | CRGCQ0805J470R | Volume Production | DigiKey | A130132CT-ND | 0.1 | 0.1
| SMA-A0207FTDT22R | SMA-A 0207 22Ω 1W 50ppm/ºC 1.00% 350V | R53 | CMP-03211-006581-1 | New From Design | Up to date | | 1 TE Connectivity | SMA-A0207FTDT22R | Volume Production | DigiKey | A0207FTDT22RCT-ND 1712-SMA- | 0.33 | 0.33
| INA180A2IDBVR | IC CURR SENSE 1 CIRCUIT SOT23-5 | U4, U5, U8, U9, U10, U11, U12, U13, U15, U16, U17, U18, U20, U21, U22, U23 | CMP-04895-000287-1 | New From Design | Up to date | 16 Texas Instruments | | INA180A2IDBVR | Volume Production | DigiKey | 296-47653-1-ND | 0.319 | 5.1
| TLV2464CDR | Quad Low Power, Rail-to-Rail Input / Output Operational Amplifier, 2.7 to 6 V, 0 to 70 degC, 14-pin SOIC (D14), Green (RoHS & no Sb/Br) | U1, U3, U14, U19 | CMP-0271-00006-3 | Released | Up to date | | 4 Texas Instruments | TLV2464CDR | Volume Production | DigiKey | 296-2436-1-ND | 3.44 | 13.76
| VJ0603Y104MXJCW1BC | | C2, C3, C4, C5, C9, C13, C14, C15, C16, C17, C18, C19, C20, C21, C22, C23, C24, C25, C26, C27, C28, C29, C30, C31, C32, C33, C34, C35, C36, C37, C38, C39, C40, C42, C43, C44, C45, C46 | CMP-2006-00058-1 | Released | Up to date | 38 Vishay | | VJ0603Y104MXJCW1BC | Volume Production | DigiKey | 720-VJ0603Y104MXJCW1BCCT-ND | 0.0438 | 2.19
| 61204021621 | WR-BHD Straight Male, Box Header, Through Hole, 2 Rows, 40 Contacts, 2.54mm Pitch | P1 | CMP-1502-00015-4 | Released | Up to date | | 1 Wurth Elektronik | 61204021621 | Volume Production | DigiKey | 732-5401-ND | 1.21 | 1.21
| C0805C104K5RACTU | CAP CER 0.1UF 50V X7R 0805 | C1 | CMP-2007-00279-2 | New From Design | Up to date | | 1 Yageo Group | C0805C104K5RACTU | Volume Production | DigiKey | 399-C0805C104K5RACTUDKR-ND | 0.13 | 0.13
| RC0805FR-071KL | Chip Resistor, 1 KOhm, +/- 1%, 125 mW, -55 to 155 degC, 0805 (2012 Metric), RoHS, Tape and Reel | R18 | CMP-2100-03671-1 | Released | Up to date | | 1 Yageo Group | RC0805FR-071KL | Volume Production | DigiKey | 311-1.00KCRDKR-ND | 0.1 | 0.1
| RC0805FR-071ML | RES 1M OHM 1% 1/ 8W 0805 | R17 | | Not managed | | | 1 Yageo Group | RC0805FR-071ML | Volume Production | DigiKey | 311-1.00MCRCT-ND | 0.1 | 0.1
| Resistor 1k +/-1% 0603 100 mW | Chip Resistor, 1 KOhm, +/-1%, 0.1 W, -55 to 155 degC, 0603 (1608 Metric) | R22, R26, R27, R28, R30, R34, R35, R36, R38, R42, R43, R44, R46, R50, R51, R52 | | Not managed | | 16 Yageo Group | | SR0603FR-07100KL | Volume Production | Mouser | 603-SR0603FR-07100KL | 0.078 | 1.25

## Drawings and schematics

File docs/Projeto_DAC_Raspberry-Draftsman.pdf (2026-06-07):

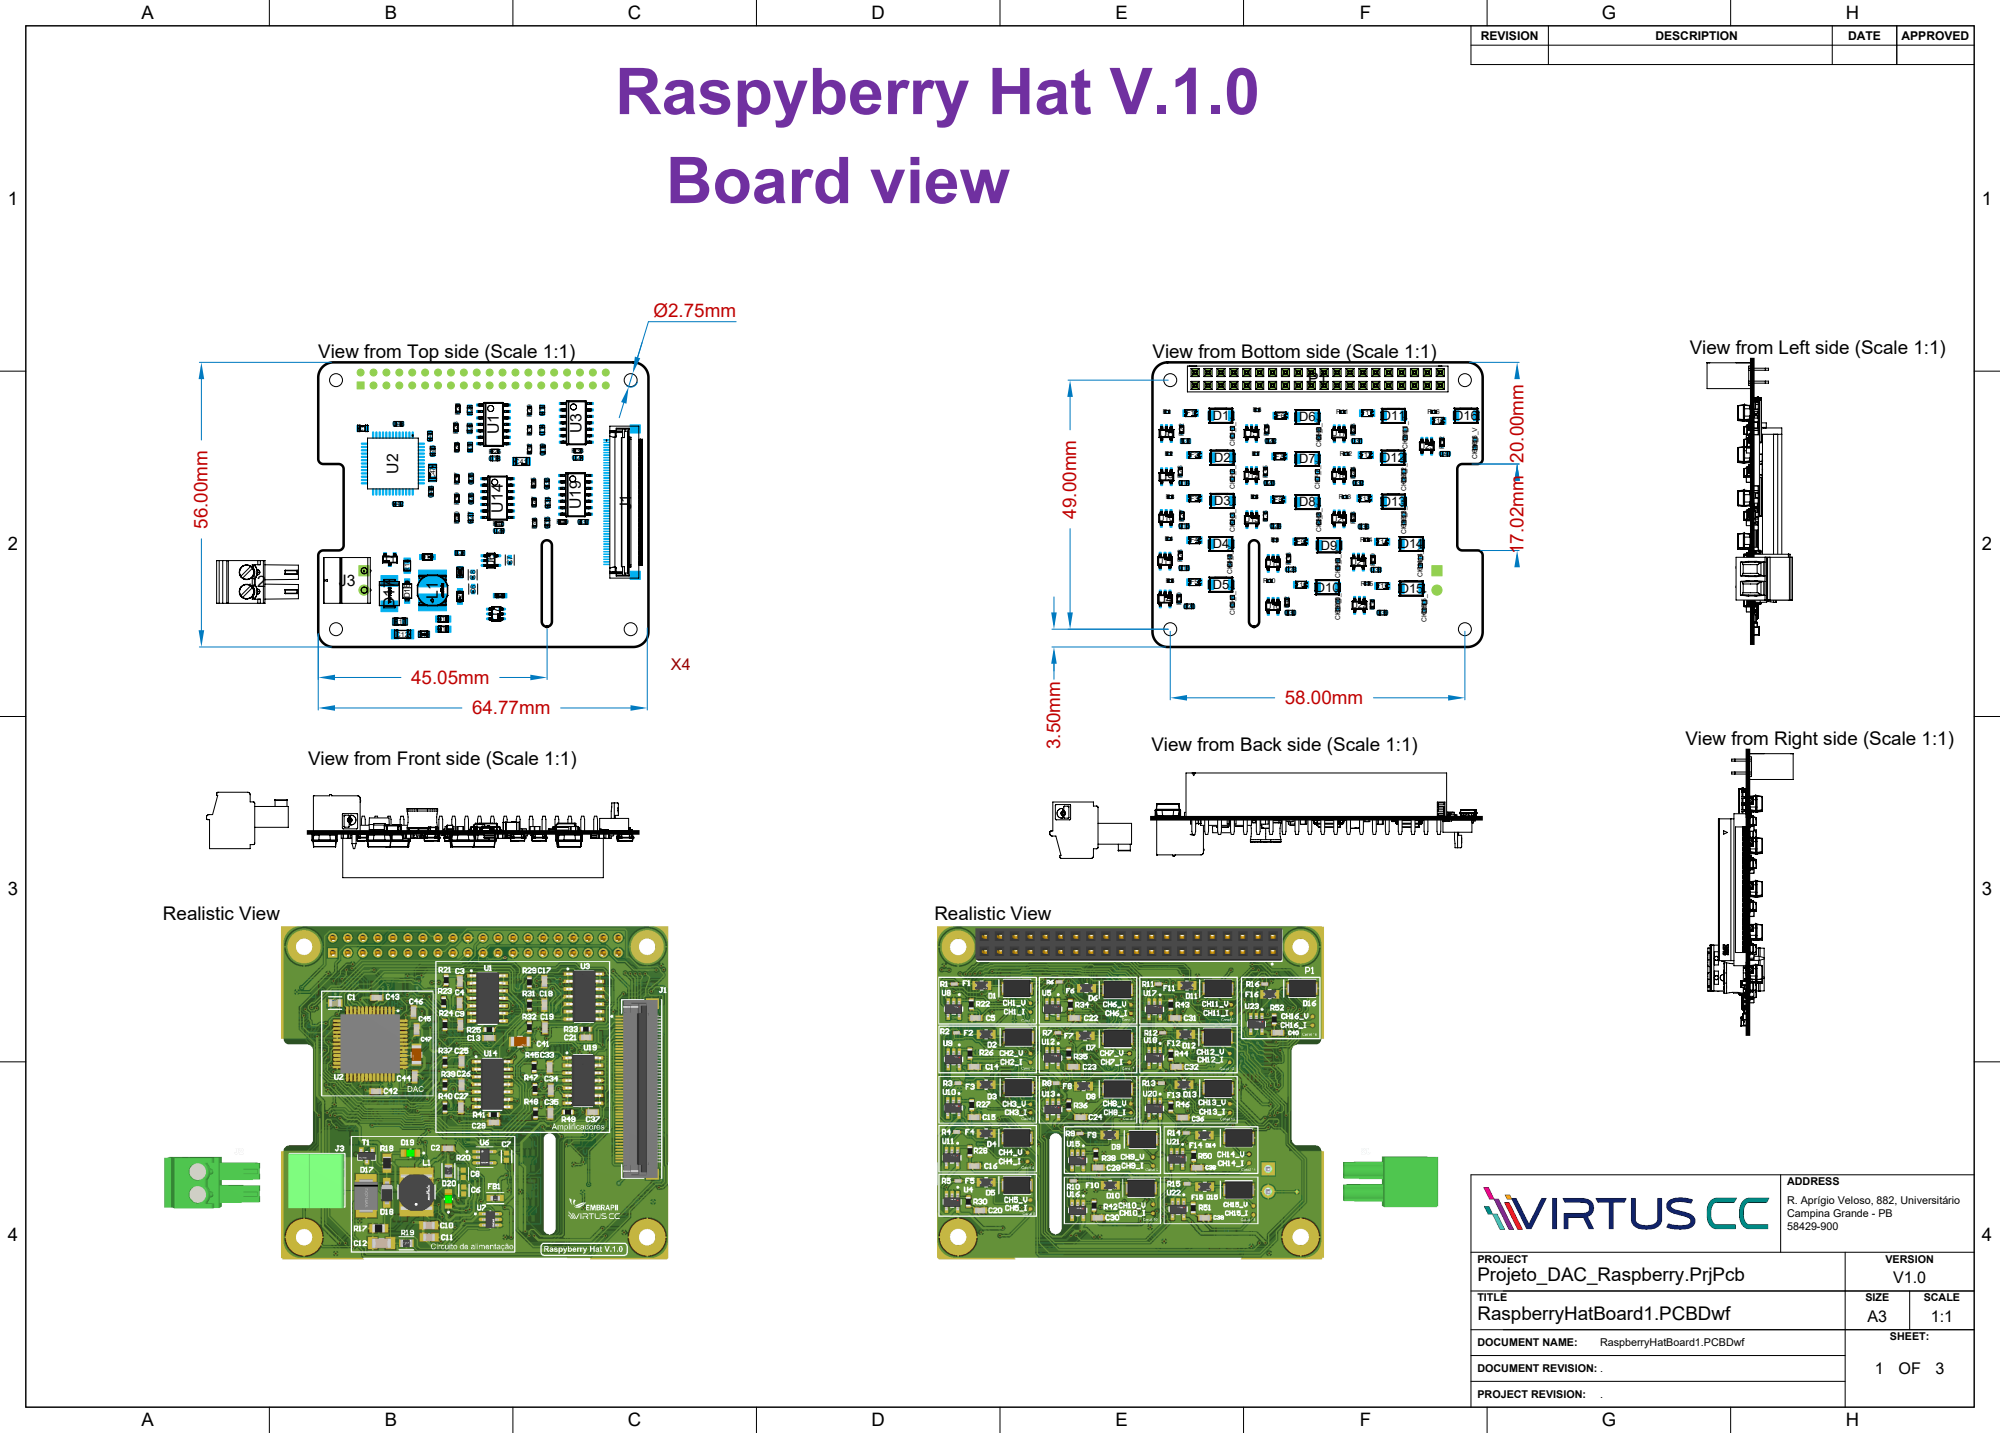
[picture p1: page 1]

View from Top side (Scale 1:1)

View from Bottom side (Scale 1:1)

View from Left side (Scale 1:1)

View from Back side (Scale 1:1)

View from Right side (Scale 1:1)

View from Front side (Scale 1:1)

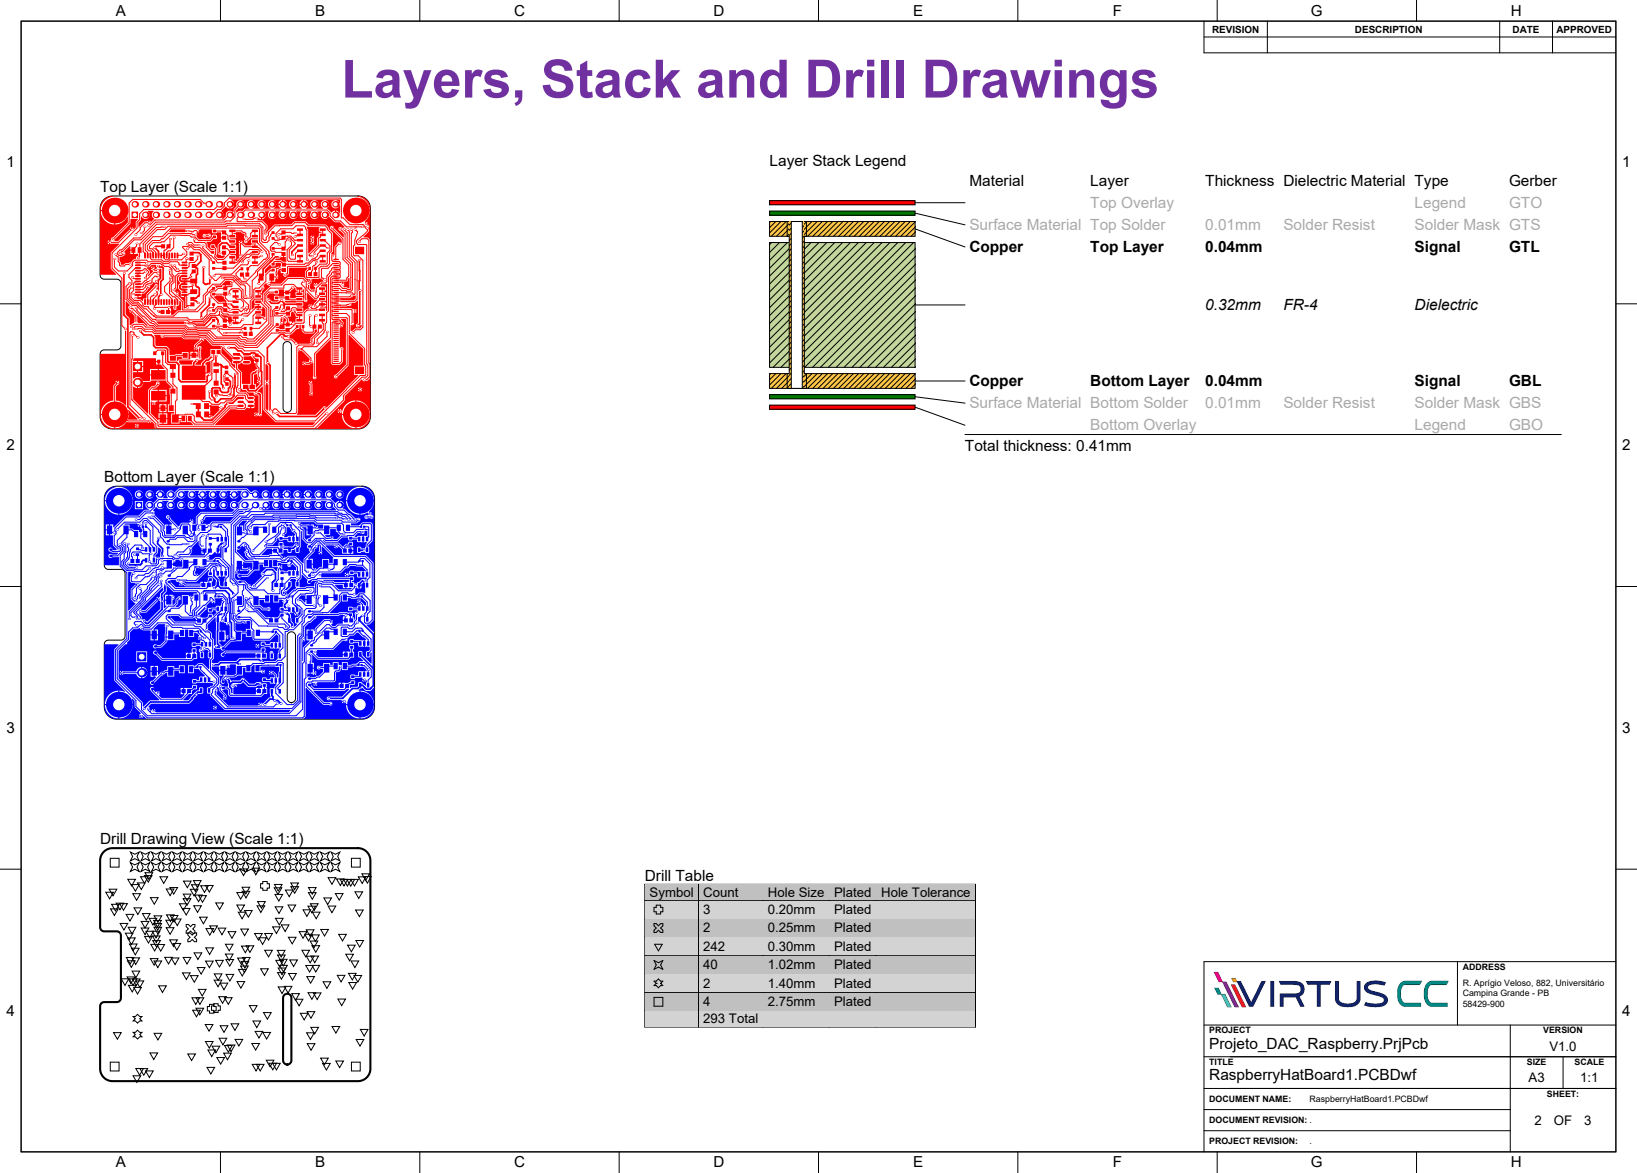
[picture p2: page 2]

Layers, Stack and Drill Drawings

Drill Drawing View (Scale 1:1)

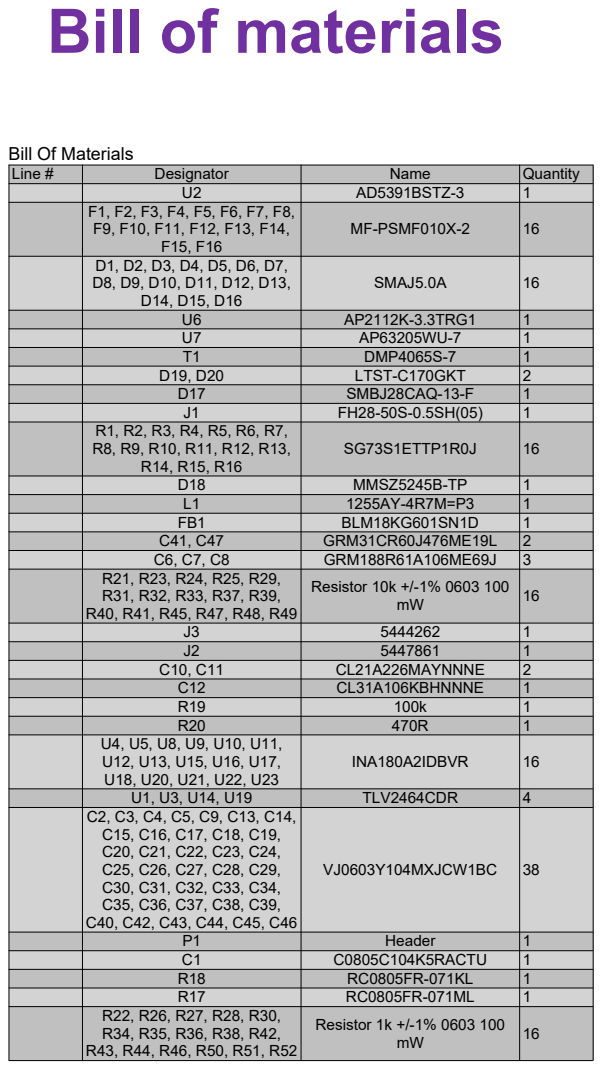
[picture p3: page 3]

Line # | Designator | Name | Quantity 1

U2 | AD5391BSTZ-3

F1, F2, F3, F4, F5, F6, F7, F8, F9, F10, F11, F12, F13, F14, F15, F16 | MF-PSMF010X-2 | 16

D1, D2, D3, D4, D5, D6, D7, D8, D9, D10, D11, D12, D13, D14, D15, D16 | SMAJ5.0A

U6 | AP2112K-3.3TRG1 | 16111211

U7 | AP63205WU-7
T1 | DMP4065S-7
D19, D20 | LTST-C170GKT
D17 | SMBJ28CAQ-13-F
J1 | FH28-50S-0.5SH(05)

R1, R2, R3, R4, R5, R6, R7, R8, R9, R10, R11, R12, R13, R14, R15, R16 | SG73S1ETTP1R0J

D18 | MMSZ5245B-TP | 1611123

L1 | 1255AY-4R7M=P3
FB1 | BLM18KG601SN1D
C41, C47 | GRM31CR60J476ME19L
C6, C7, C8 | GRM188R61A106ME69J

R21, R23, R24, R25, R29, R31, R32, R33, R37, R39, R40, R41, R45, R47, R48, R49 | Resistor 10k +/-1% 0603 100 mW

J2 | 5447861
C10, C11 | CL21A226MAYNNNE
C12 | CL31A106KBHNNNE
R19 | 100k
R20 | 470R

U4, U5, U8, U9, U10, U11, U12, U13, U15, U16, U17, U18, U20, U21, U22, U23 | INA180A2IDBVR | 164

U1, U3, U14, U19 | TLV2464CDR
C2, C3, C4, C5, C9, C13, C14, C15, C16, C17, C18, C19, C20, C21, C22, C23, C24, C25, C26, C27, C28, C29, C30, C31, C32, C33, C34, C35, C36, C37, C38, C39, C40, C42, C43, C44, C45, C46 | VJ0603Y104MXJCW1BC | 381111

P1 | Header
C1 | C0805C104K5RACTU
R18 | RC0805FR-071KL
R17 | RC0805FR-071ML

R22, R26, R27, R28, R30, R34, R35, R36, R38, R42, R43, R44, R46, R50, R51, R52 | Resistor 1k +/-1% 0603 100 mW | 16

ADDRESS R. Aprígio Veloso, 882, Universitário Campina Grande - PB 58429-900

PROJECT Projeto_DAC_Raspberry.PrjPcb | VERSION V1.0
TITLE RaspberryHatBoard1.PCBDwf | SIZE A3 | SCALE

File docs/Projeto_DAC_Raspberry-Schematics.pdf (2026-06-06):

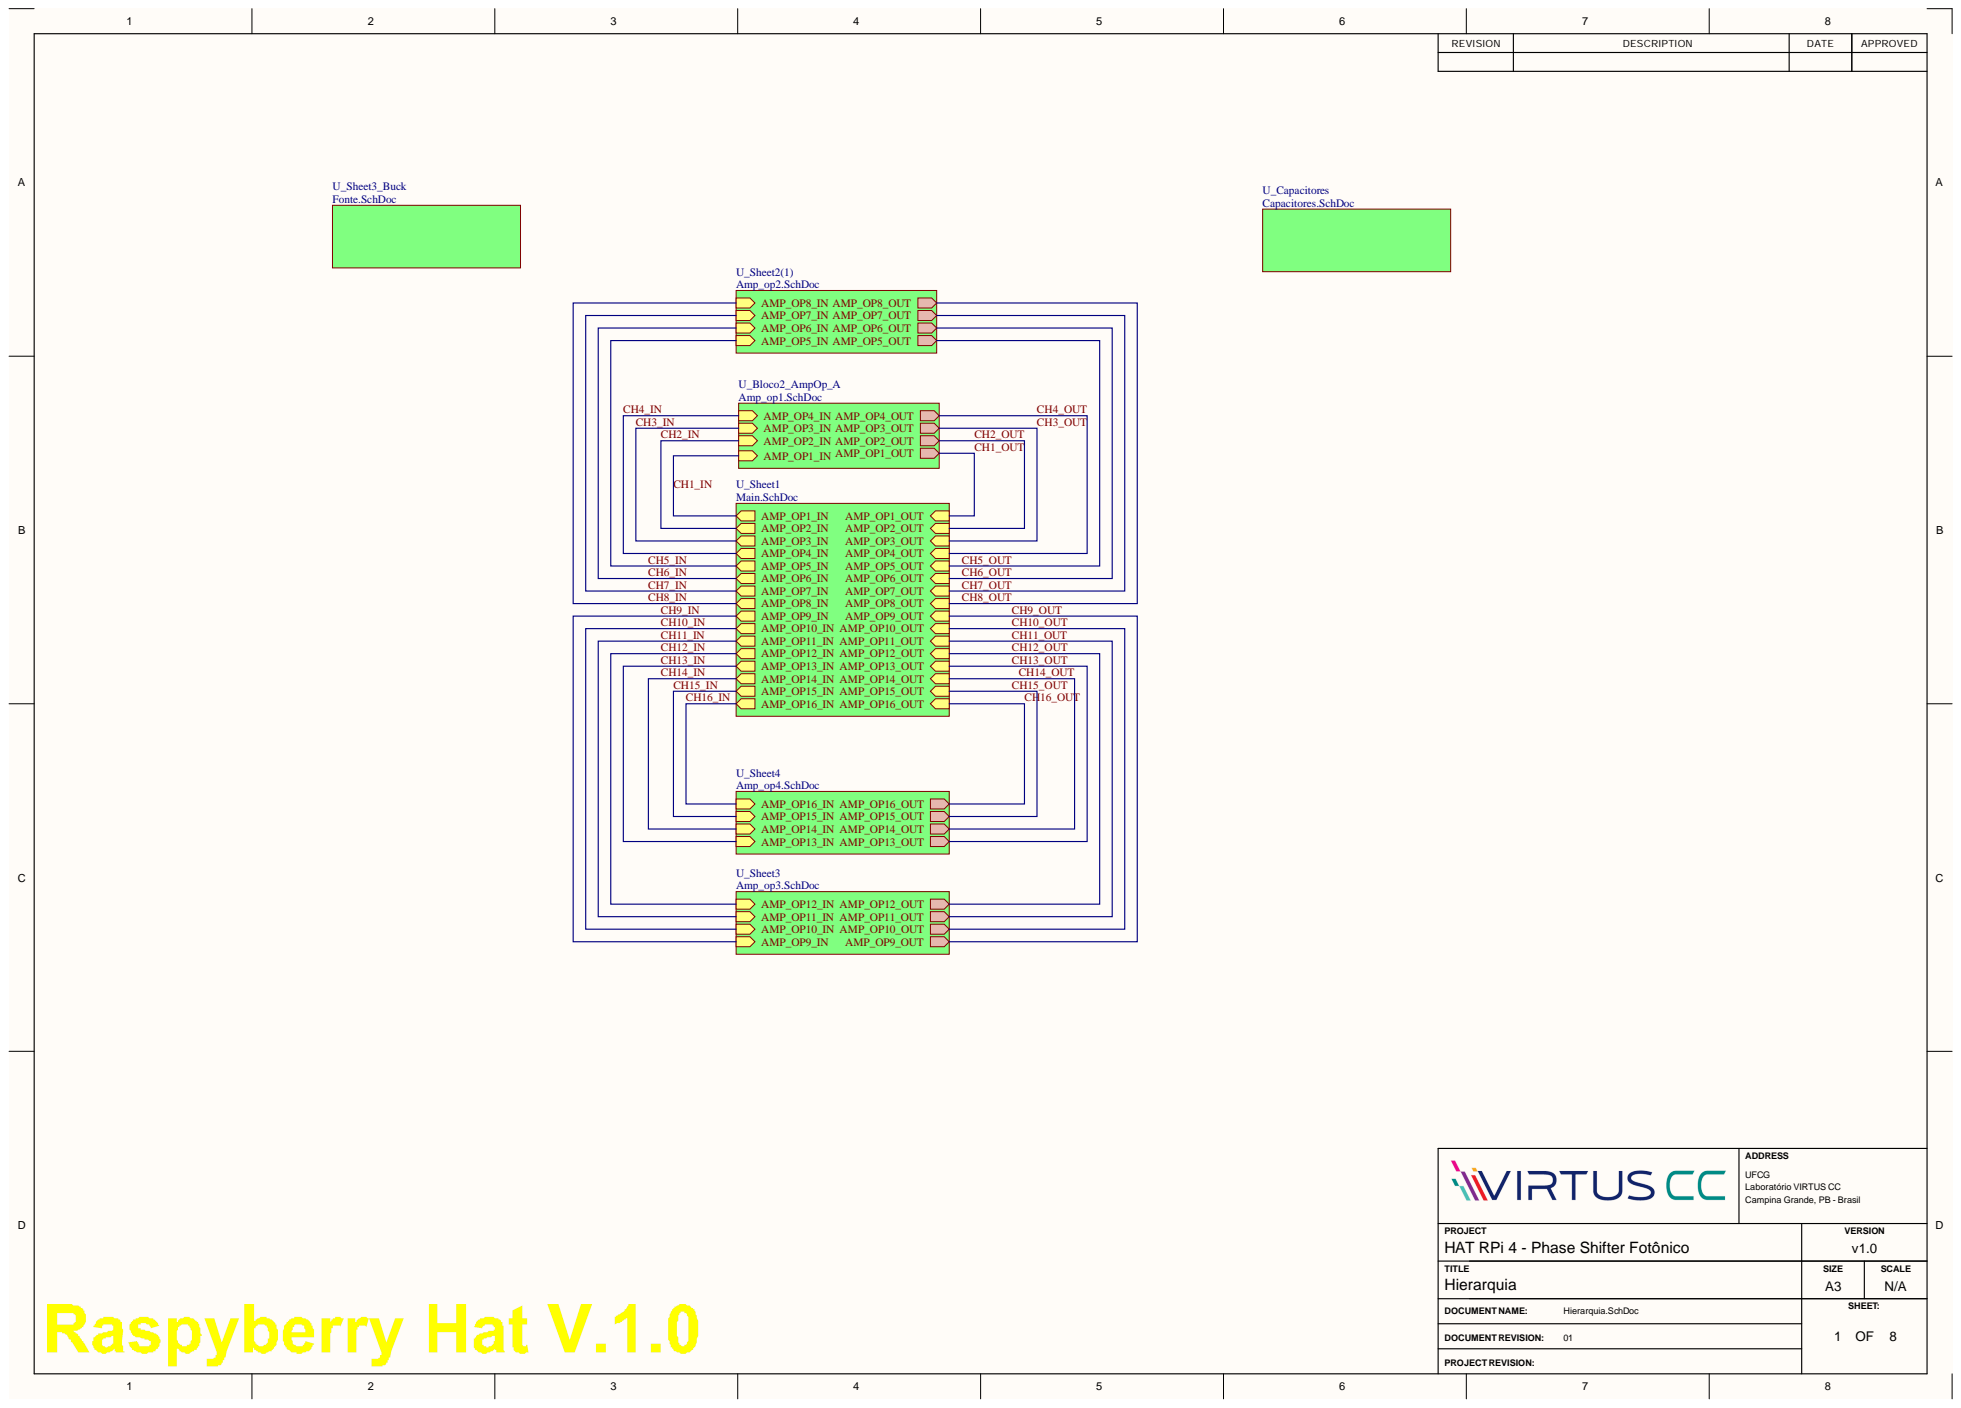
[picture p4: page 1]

CH3_IN | | CH3_OUT
CH2_IN | | CH2_OUT

CH1_OUT

CH10_IN | CH10_OUT
CH11_IN | CH11_OUT
CH12_IN | CH12_OUT
CH13_IN | CH13_OUT
CH14_IN | CH14_OUT
CH15_IN | CH15_OUT CH16_OUT

ADDRESS UFCG Laboratório VIRTUS CC Campina Grande, PB - Brasil

PROJECT HAT RPi 4 - Phase Shifter Fotônico | VERSION v1.0

TITLE Hierarquia | SIZE A3 | SCALE N/A

DOCUMENT NAME: Hierarquia.SchDoc | SHEET: 1 OF 8

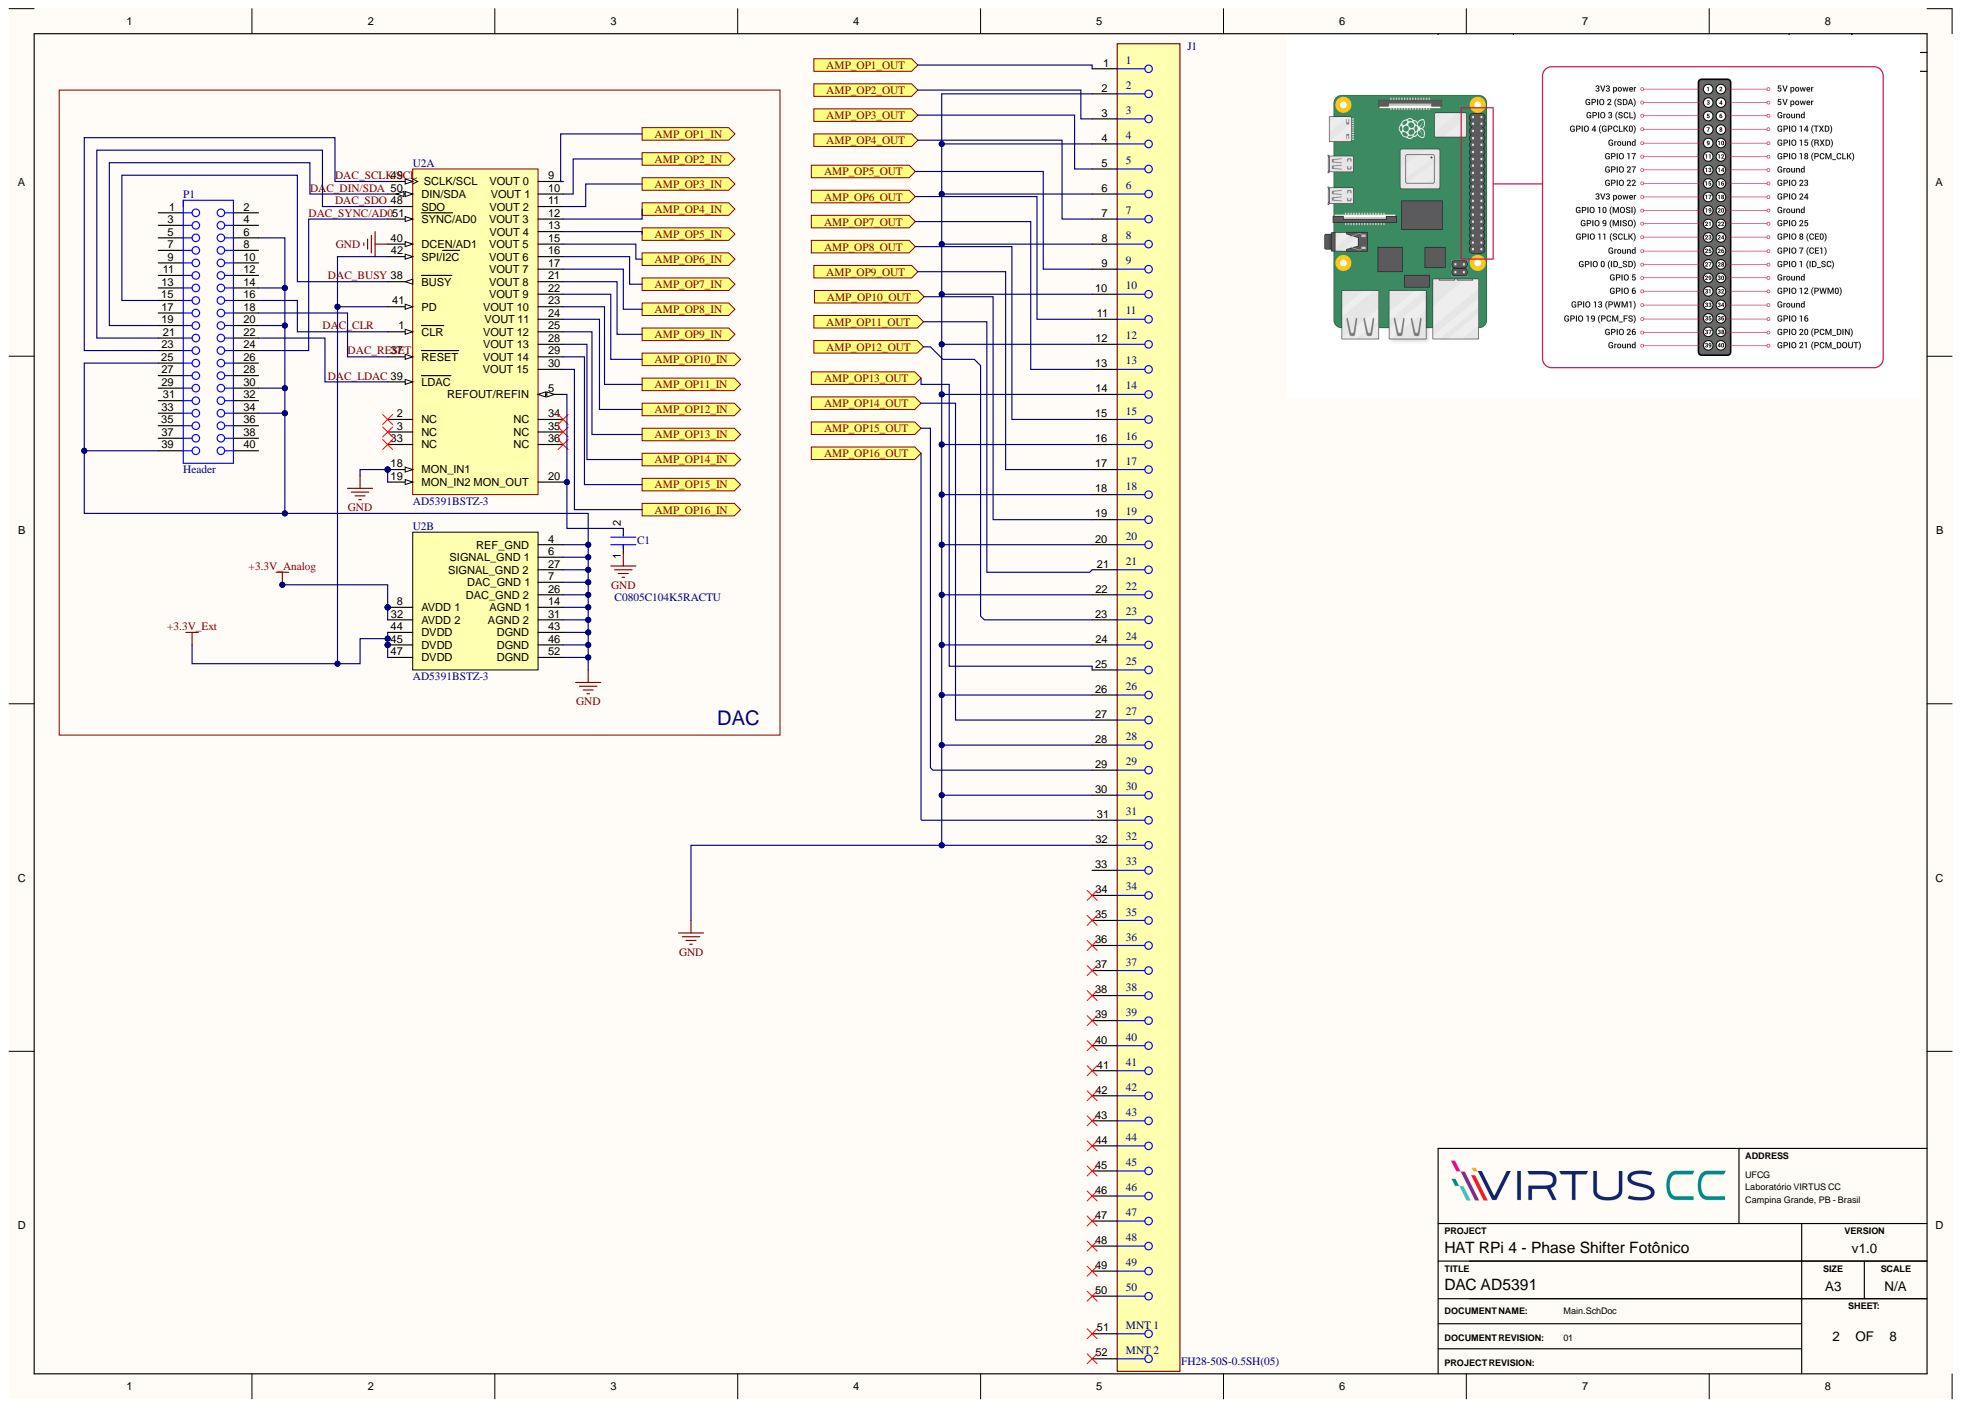
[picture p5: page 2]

ADDRESS UFCG Laboratório VIRTUS CC Campina Grande, PB - Brasil

PROJECT HAT RPi 4 - Phase Shifter Fotônico | VERSION v1.0

TITLE DAC AD5391 | SIZE A3 | SCALE N/A

DOCUMENT NAME: Main.SchDoc | SHEET: 2 8

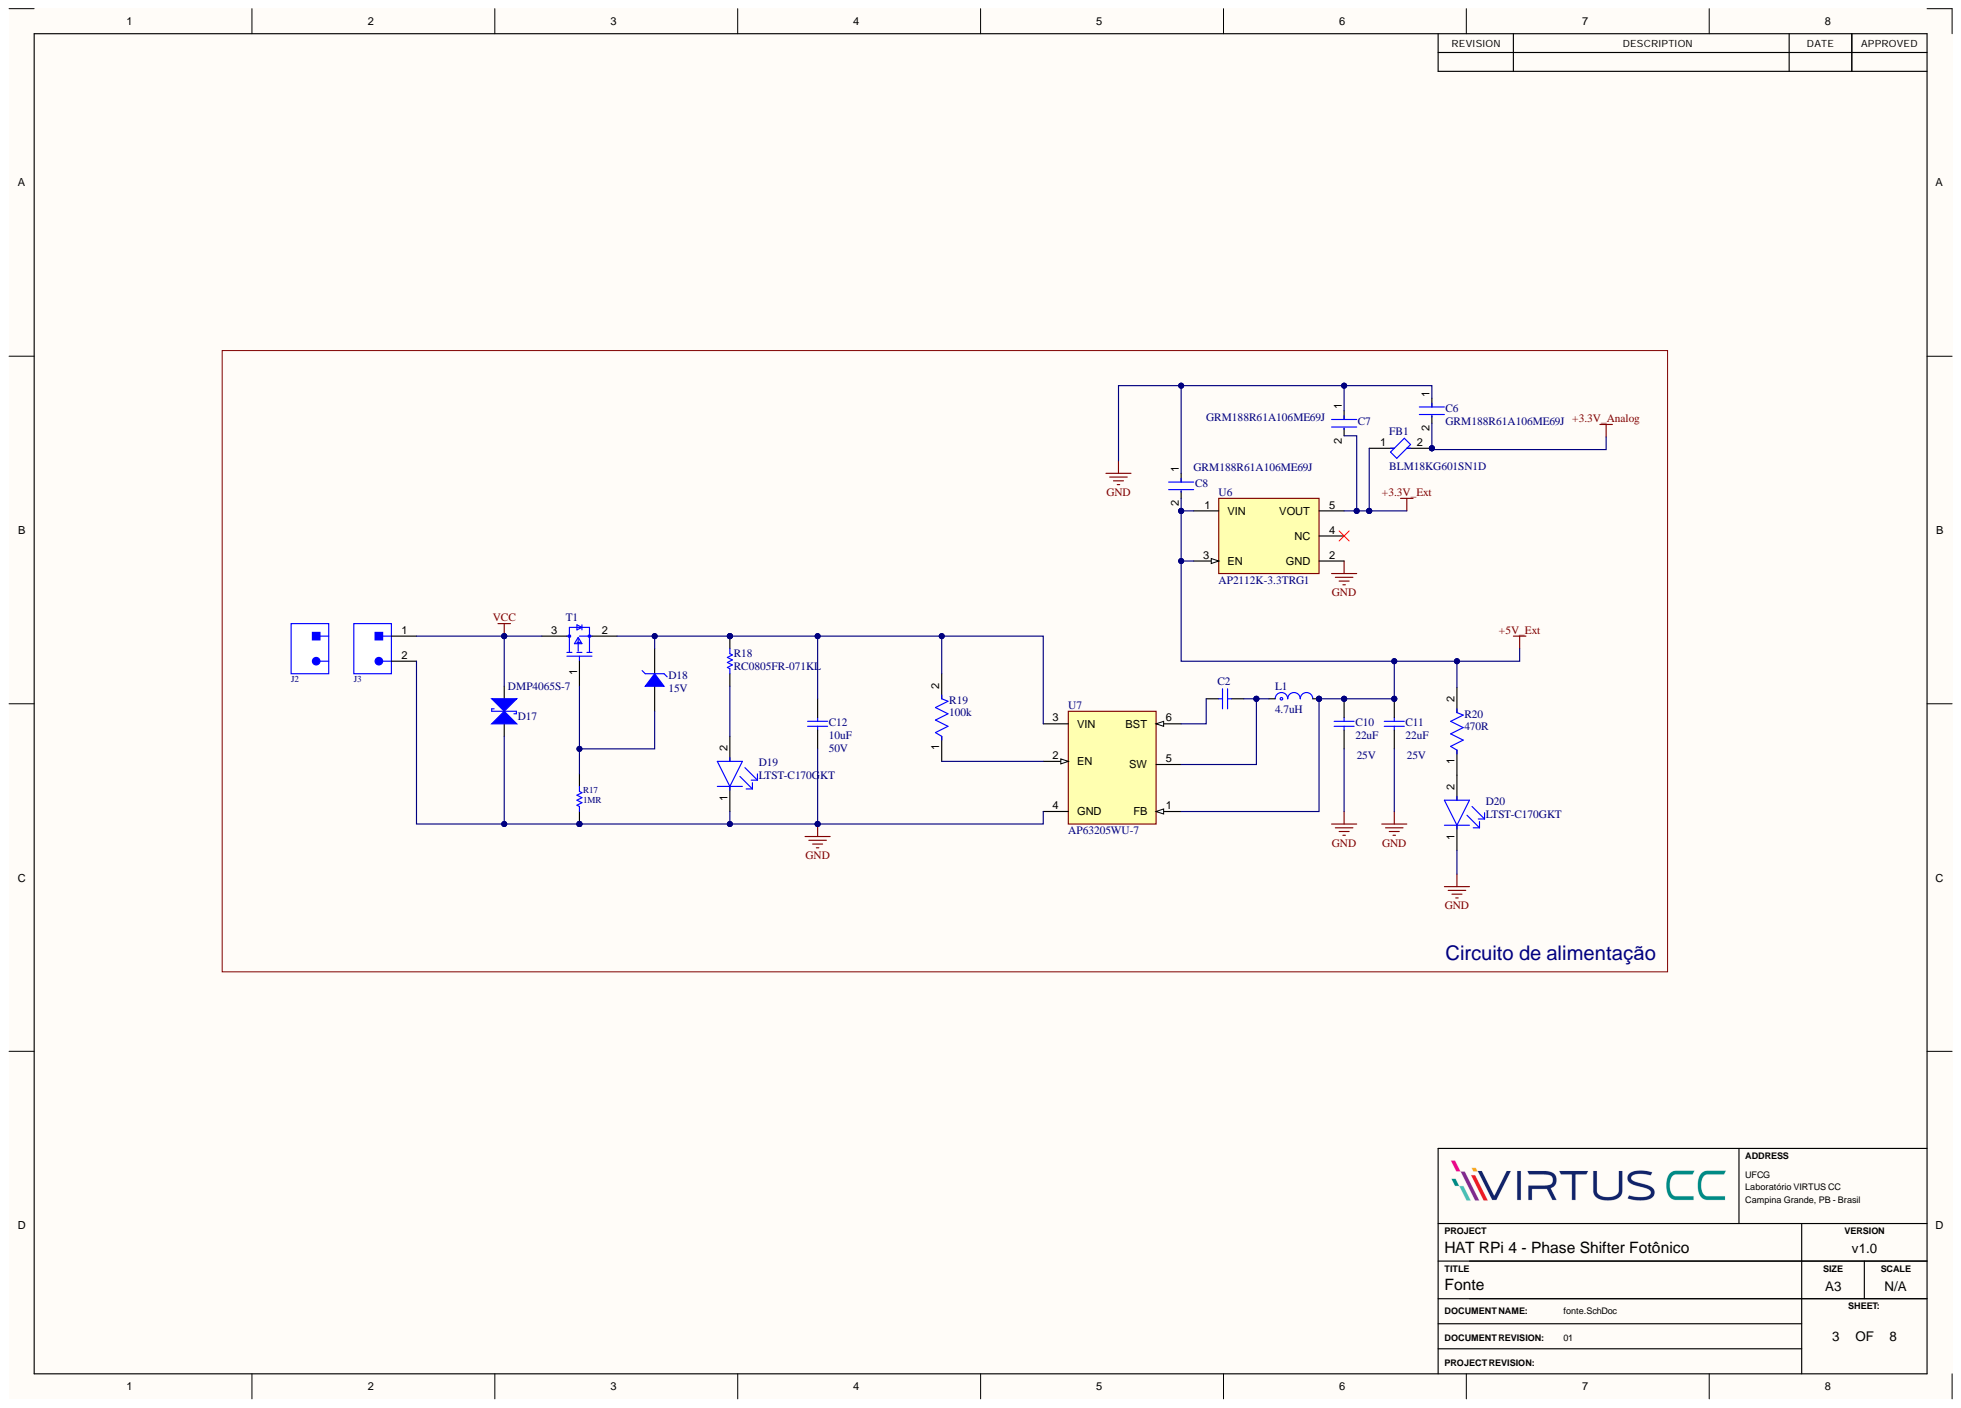
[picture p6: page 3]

ADDRE S S UF C G Laborat ó rio VIR TUS CC Campina Grande, P B -B rasil

PROJE C T HAT RPi 4 - Phase Shifter Fot ônico | V ERSIO N
TIT L E Font e | v1.0 SHEET: SIZ E A3 | SCAL E N/A

DOCUM ENT NAM : fonte.S c h o c

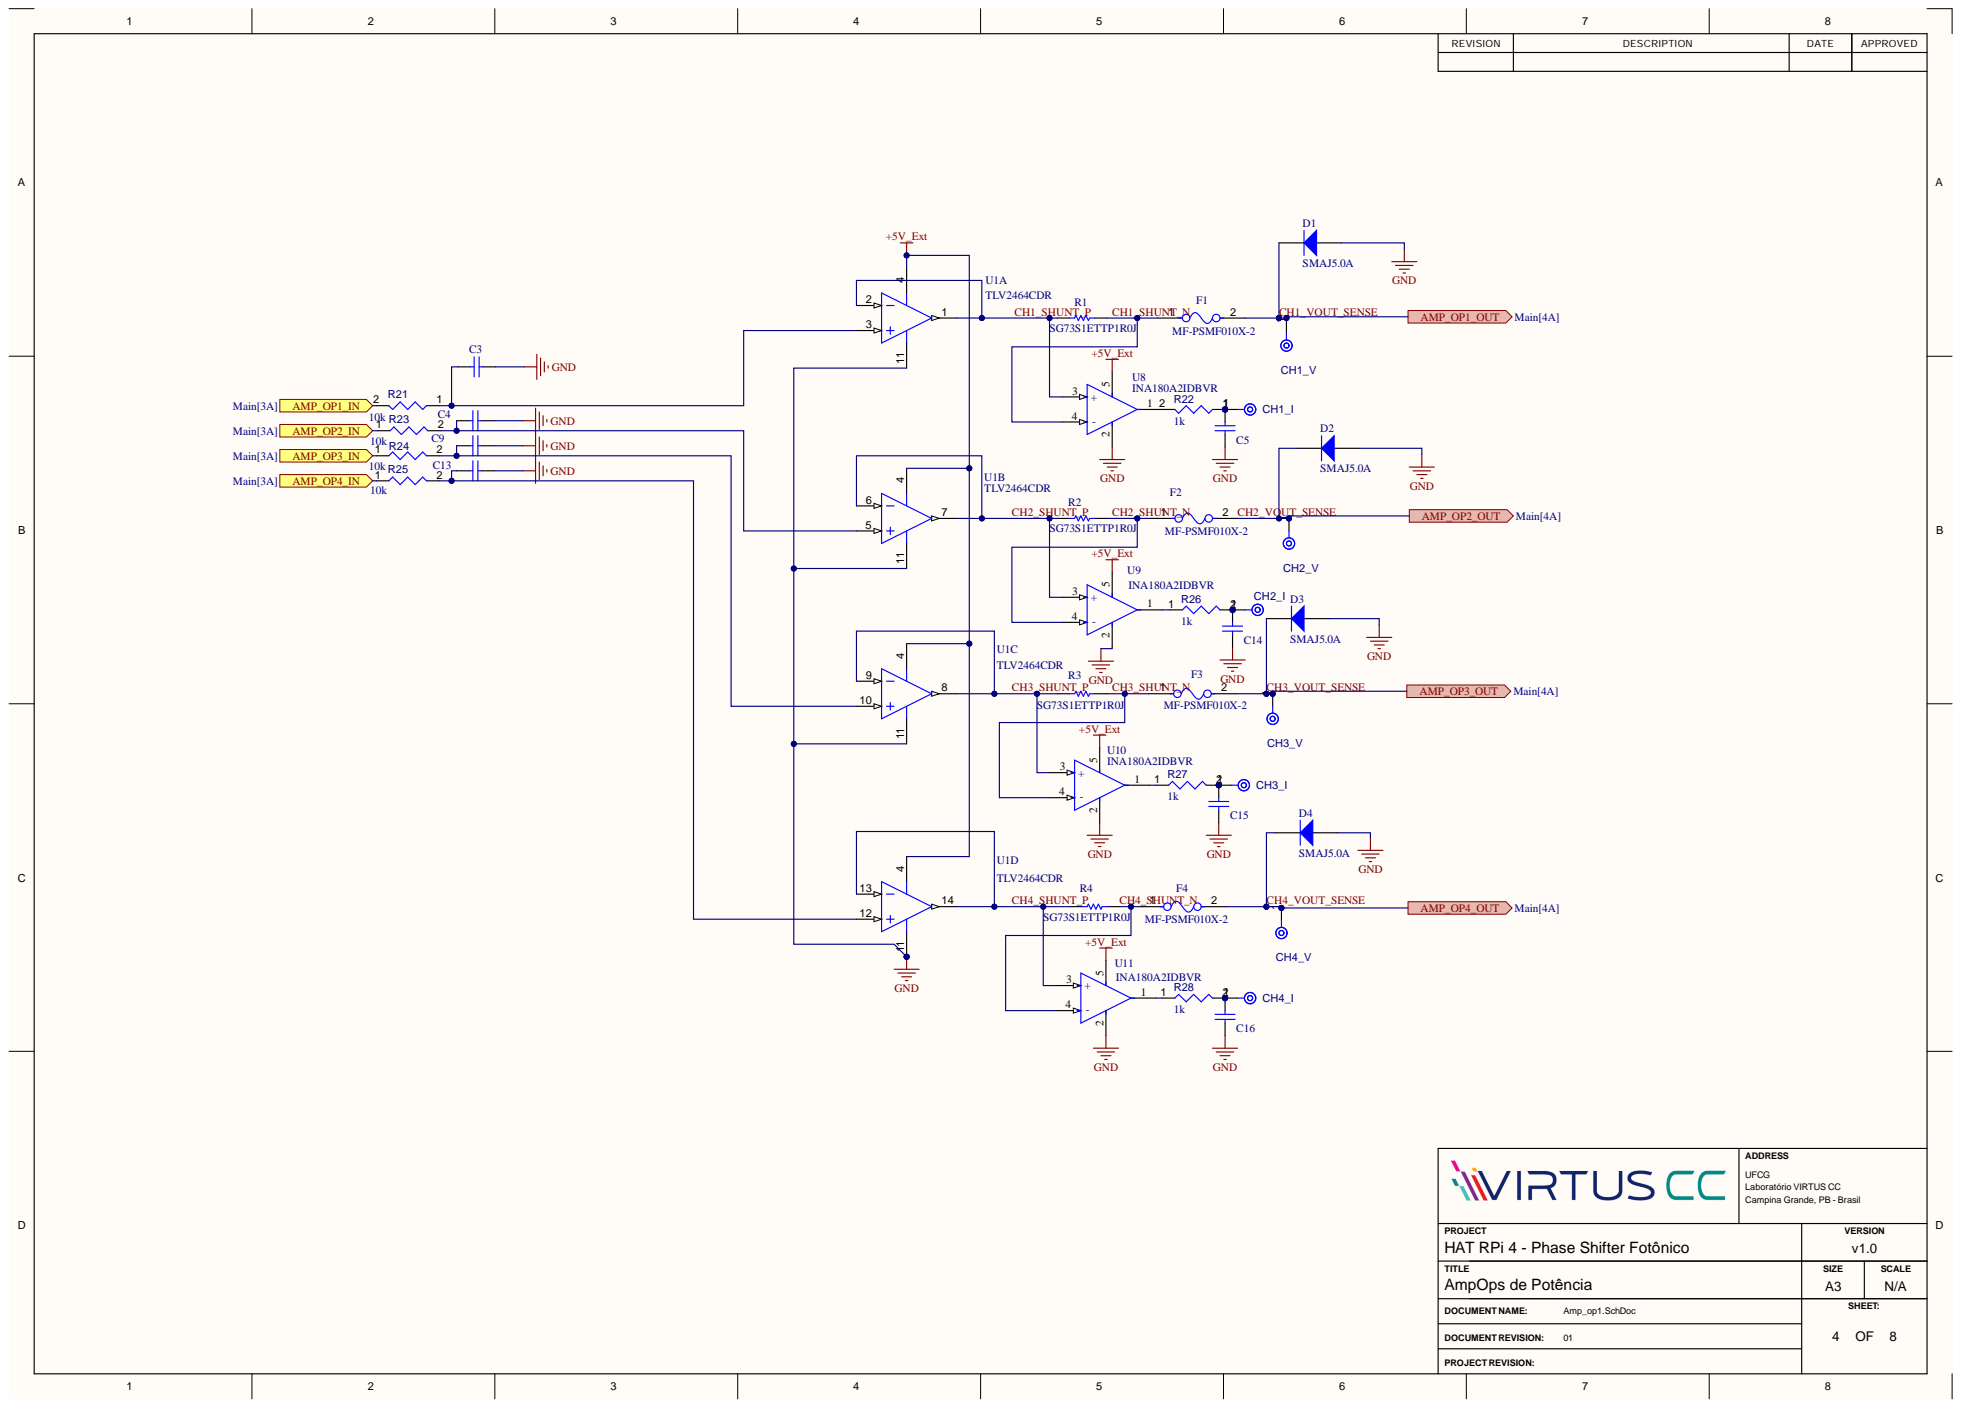
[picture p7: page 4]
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

PROJE C T HAT RPi 4 - Phase Shifter Fot ônico | V ERSIO N
TIT L E AmpOps de Pot | v1.0 SHEET: SIZ E | SCAL E N/A

ência | A3 Amp_op1.SchDoc 4

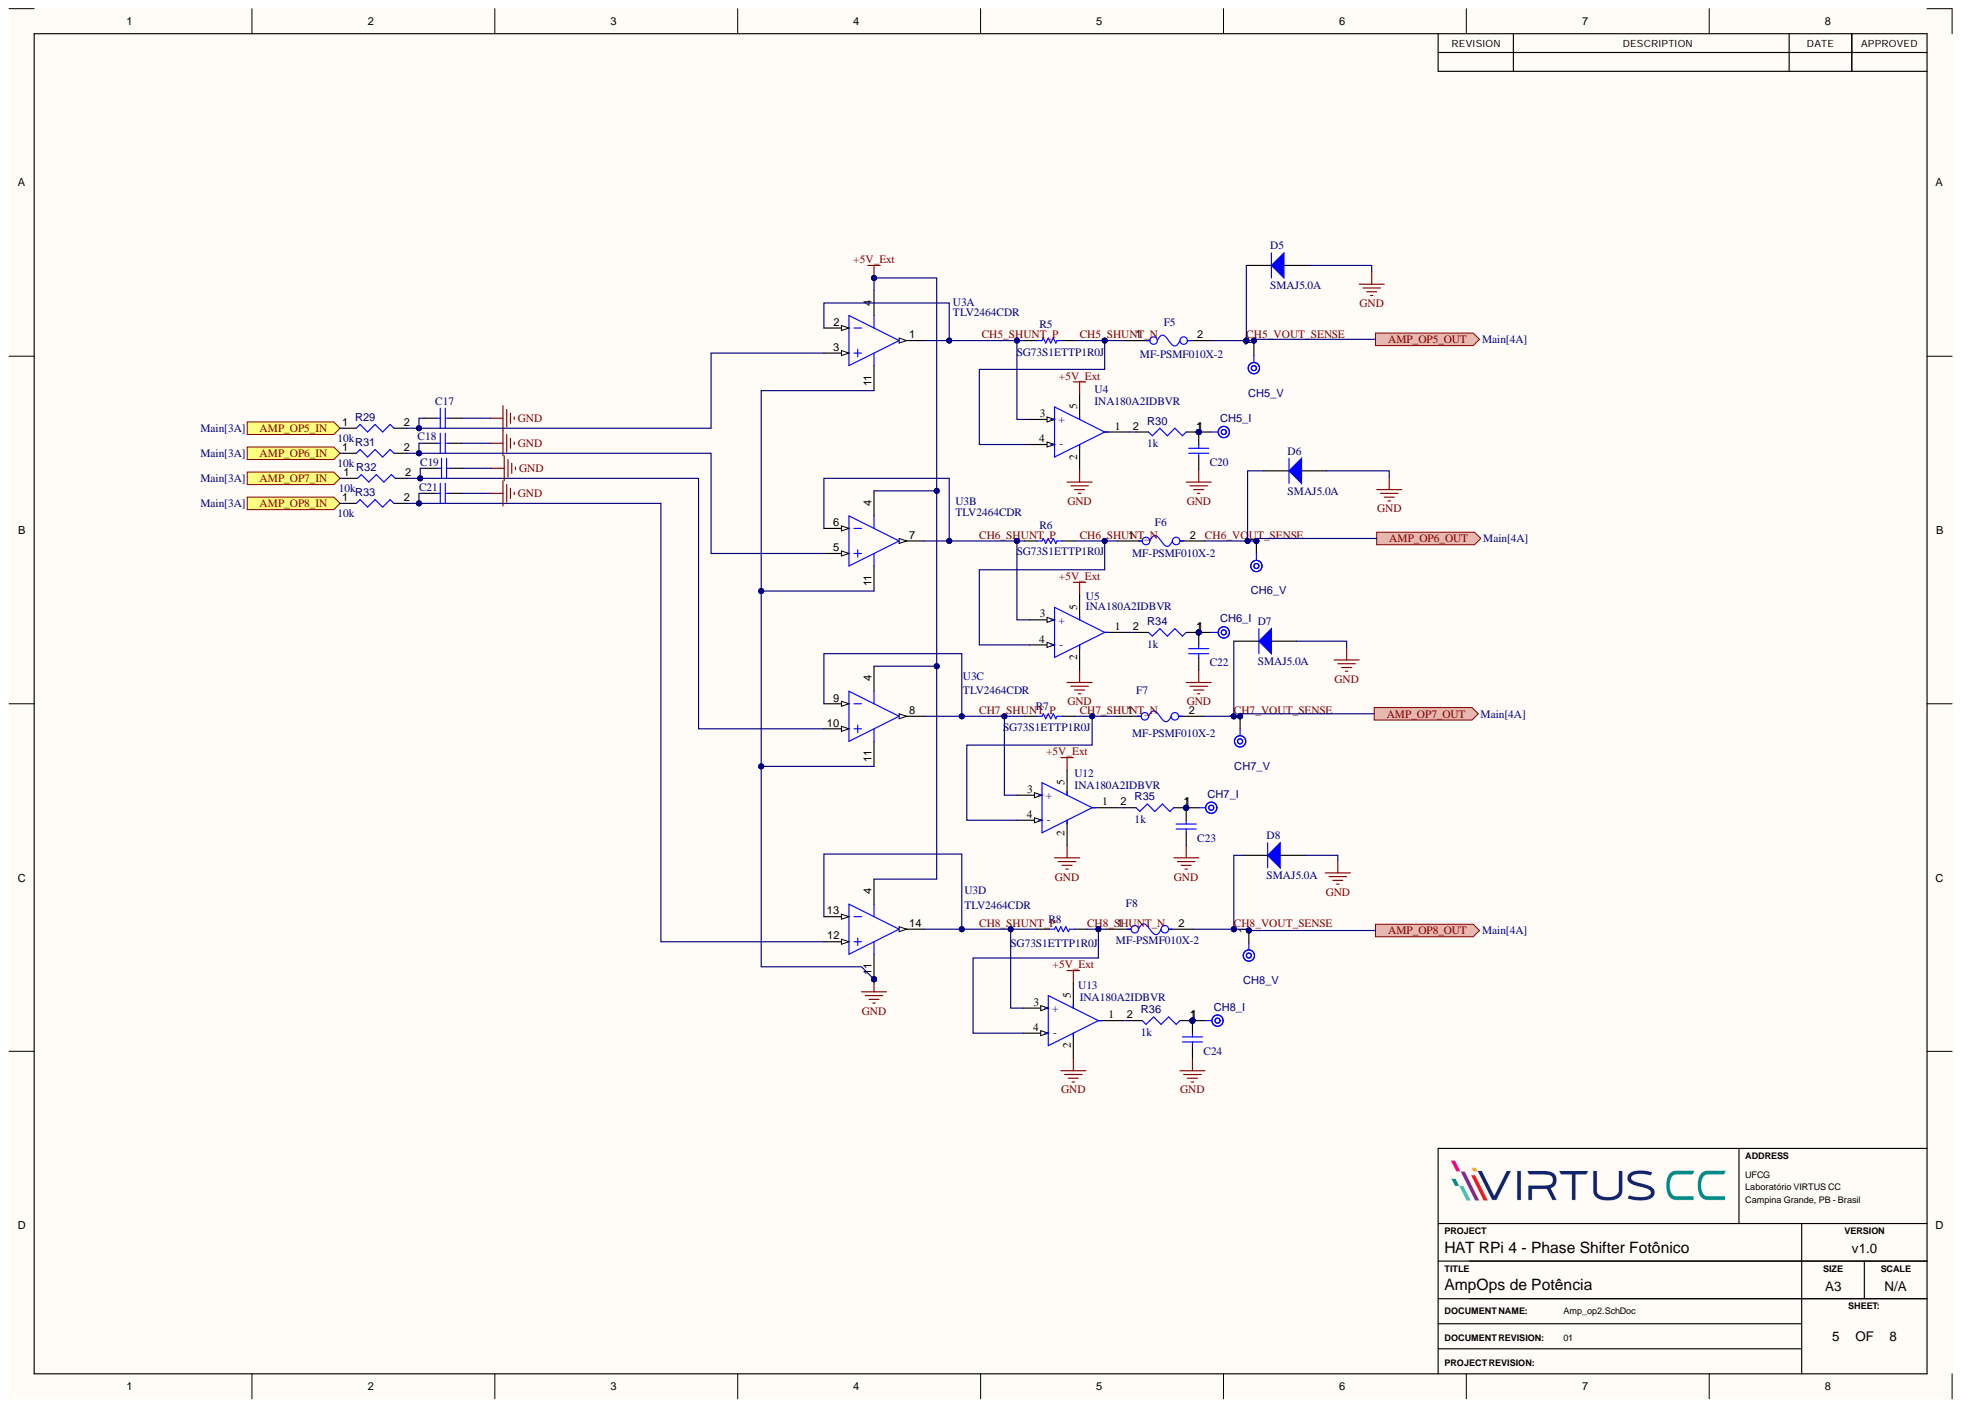
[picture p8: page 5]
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

ência | A3 Amp_op2.SchDoc 5

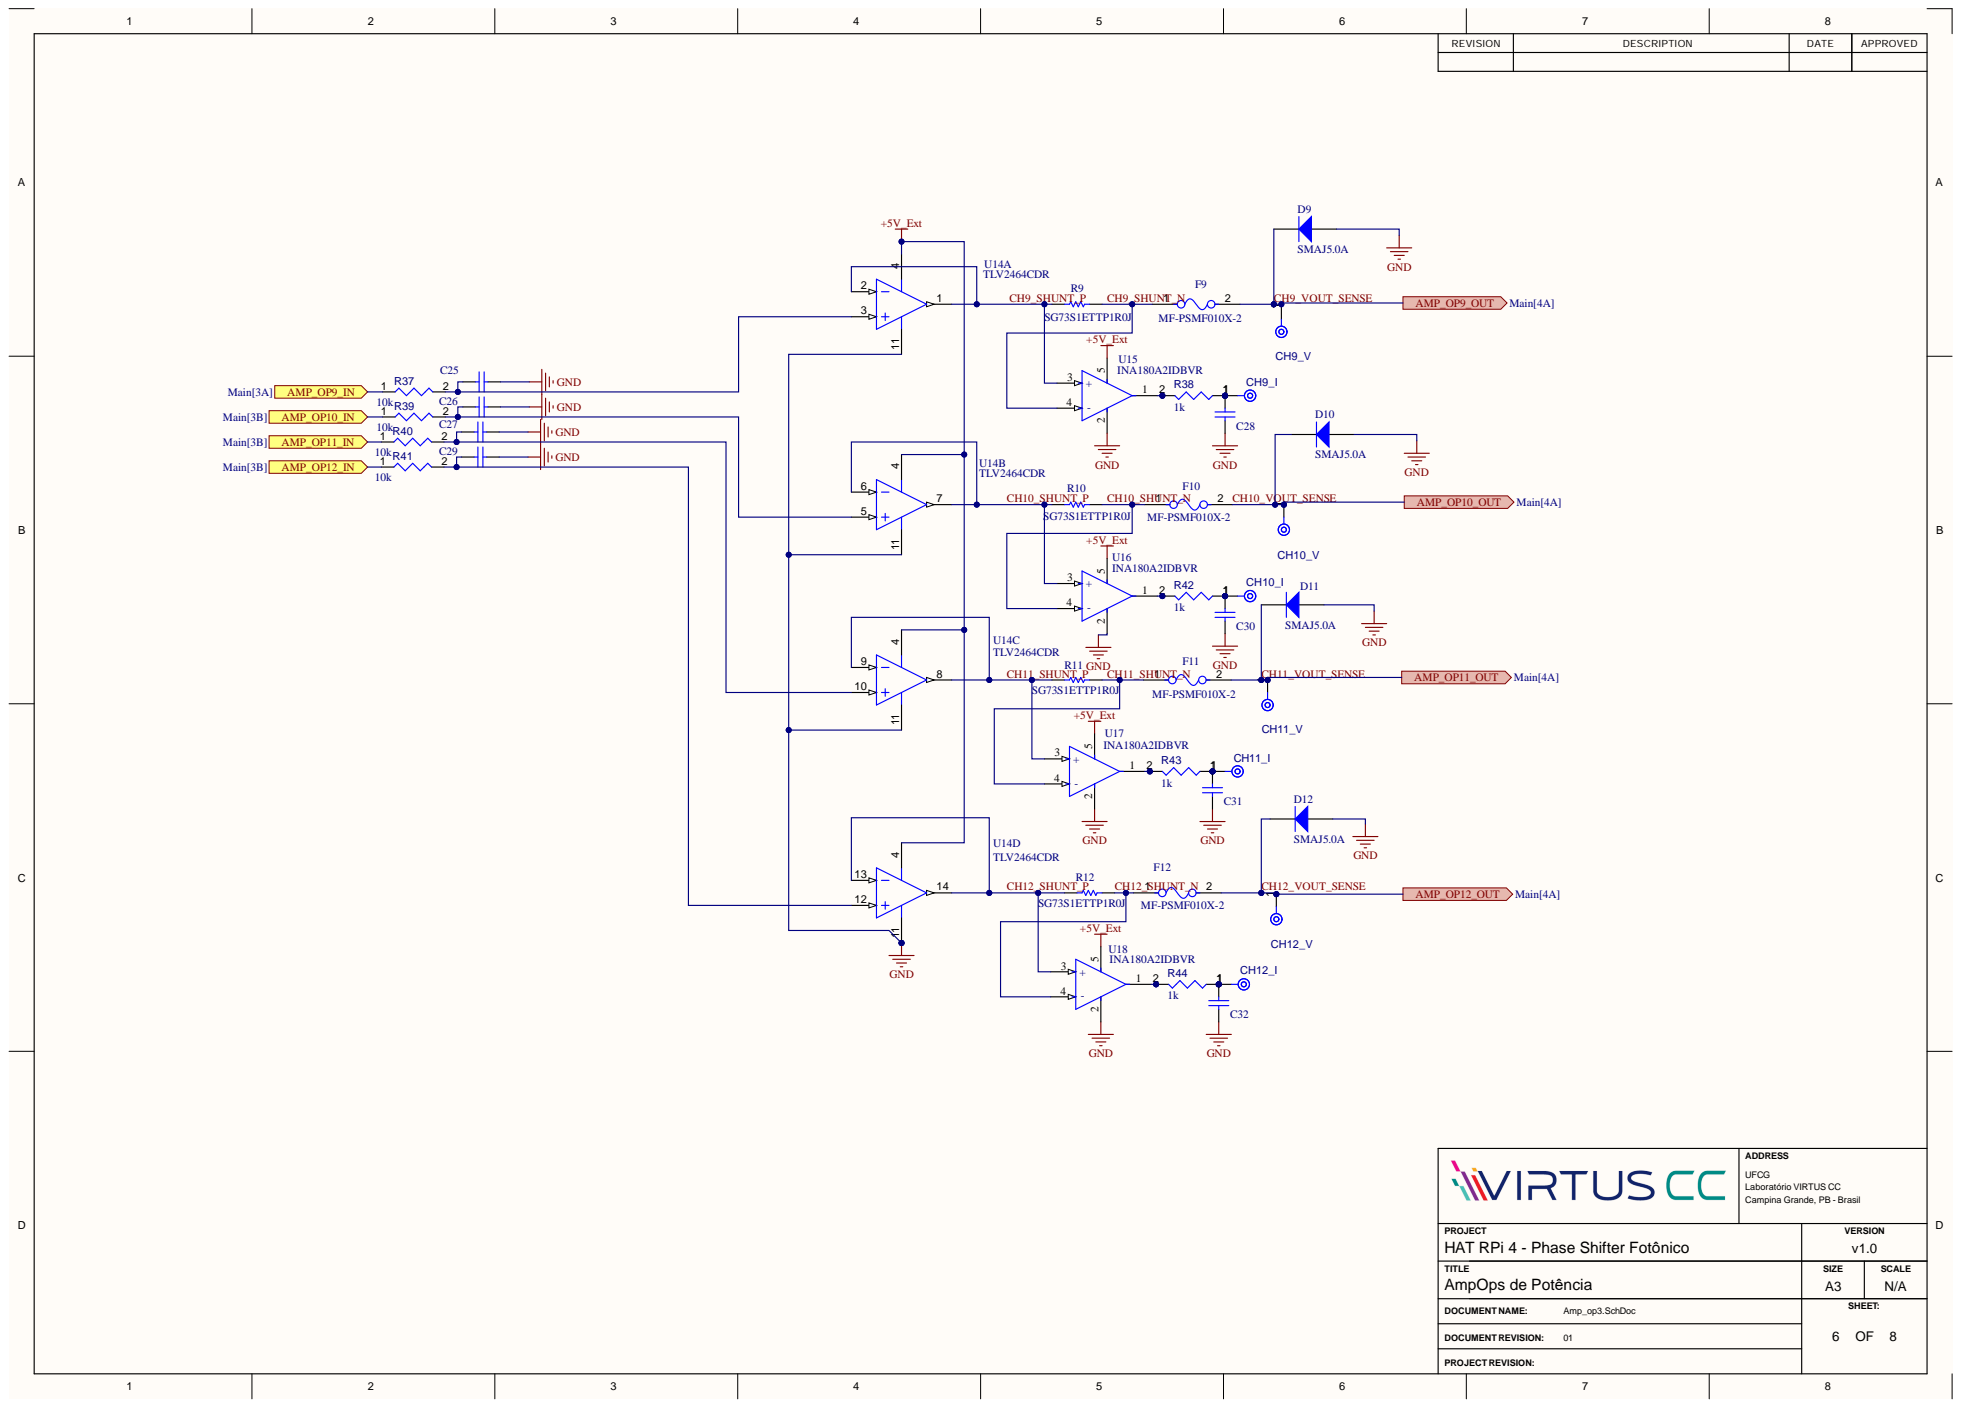
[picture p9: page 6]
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

ência | A3 Amp_op3.SchDoc 6

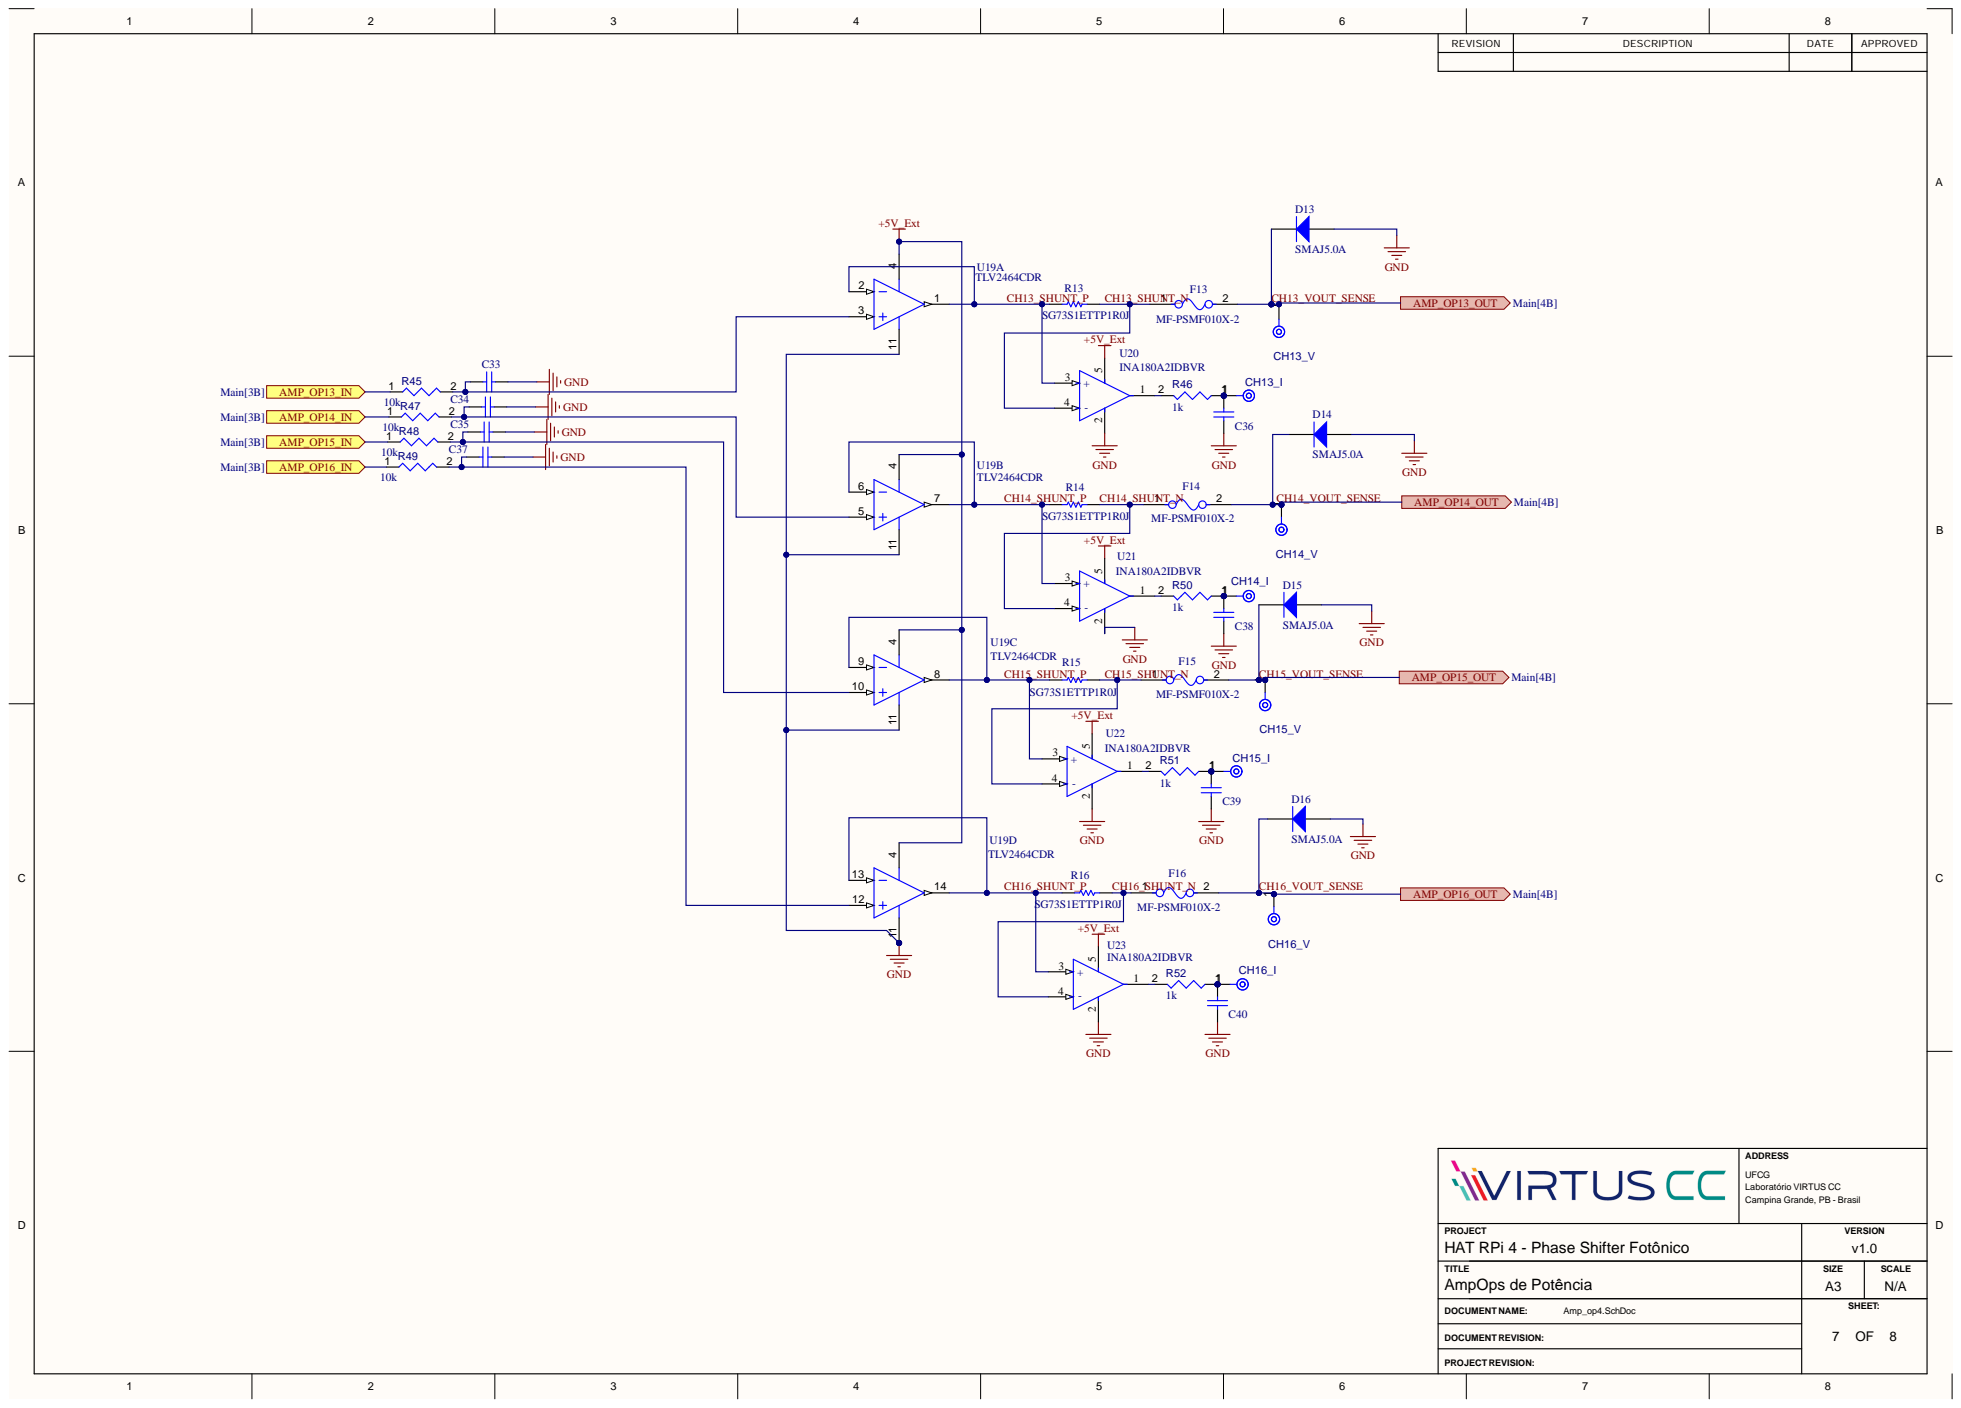
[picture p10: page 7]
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

ência | A3 Amp_op4.SchDoc 7

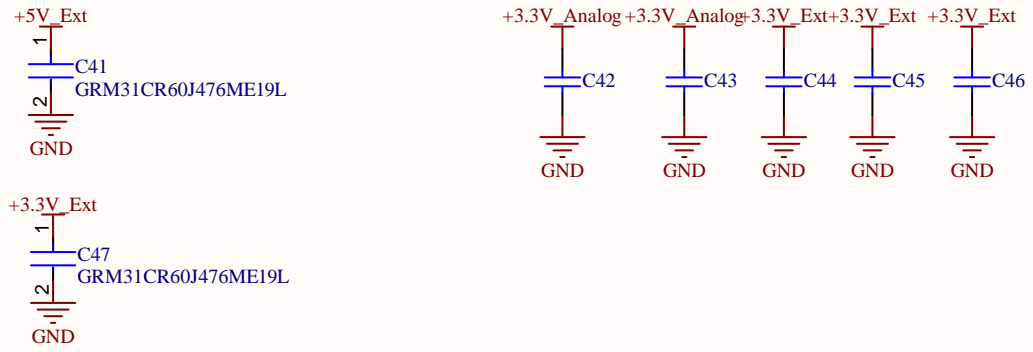
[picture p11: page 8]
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

PROJE C T HAT RPi 4 - Phase Shifter Fot ônico | V ERSIO N
TIT L E Filtros | v1.0 SHEET: SIZ E A3 | SCAL E N/A

Capacitores. c h o c

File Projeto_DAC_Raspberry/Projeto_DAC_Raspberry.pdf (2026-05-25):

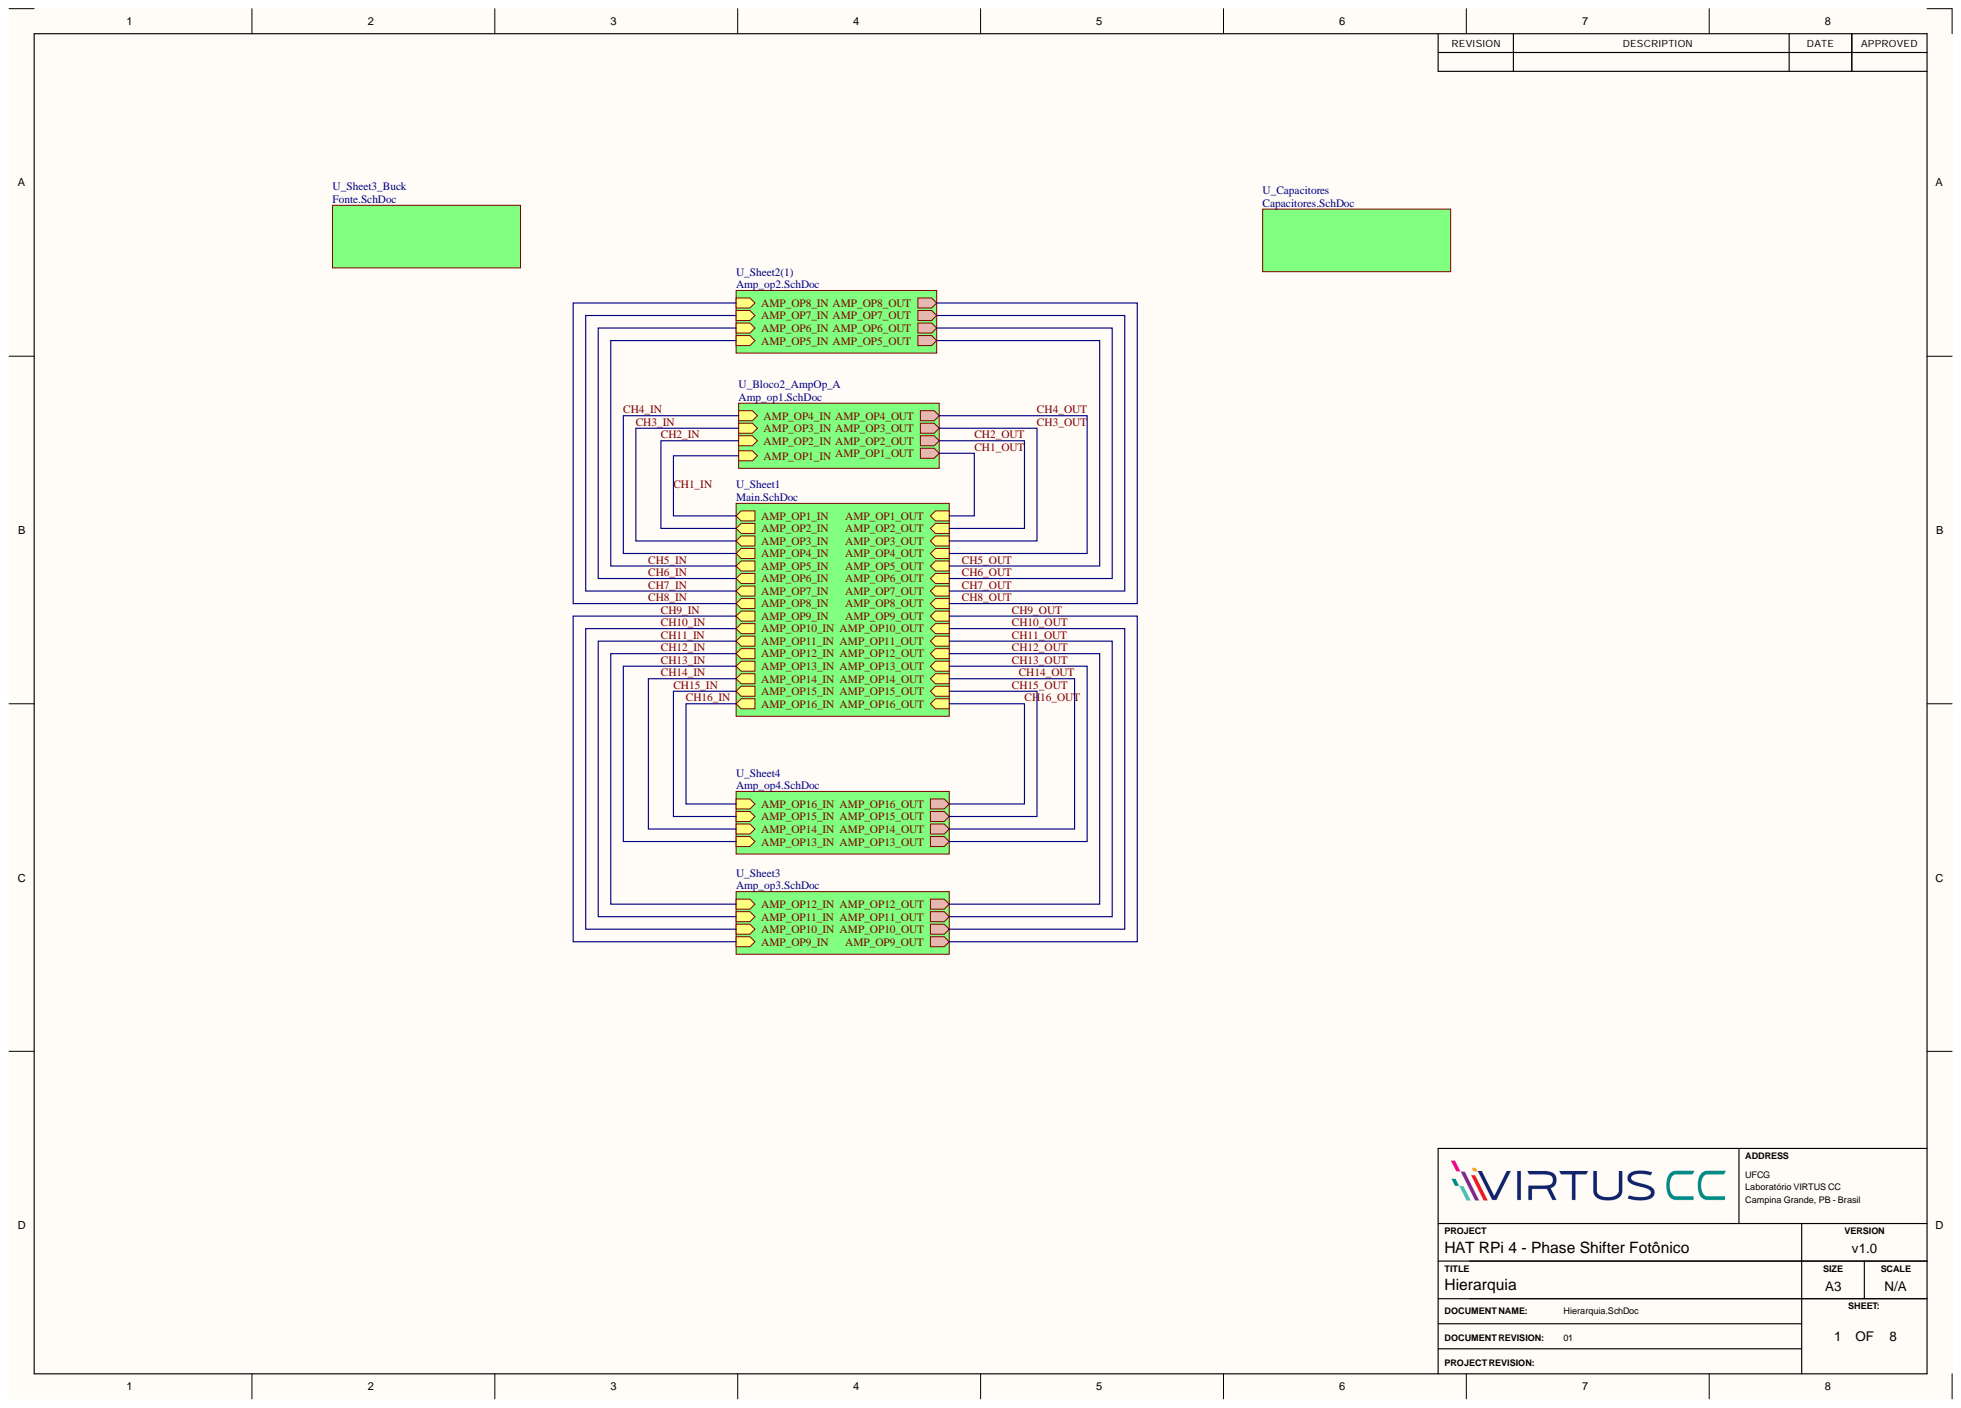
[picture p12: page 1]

CH3_IN | | CH3_OUT
CH2_IN | | CH2_OUT

CH1_OUT

CH10_IN | CH10_OUT
CH11_IN | CH11_OUT
CH12_IN | CH12_OUT
CH13_IN | CH13_OUT
CH14_IN | CH14_OUT
CH15_IN | CH15_OUT CH16_OUT

ADDRESS UFCG Laboratório VIRTUS CC Campina Grande, PB - Brasil

PROJECT HAT RPi 4 - Phase Shifter Fotônico | VERSION v1.0

TITLE Hierarquia | SIZE A3 | SCALE N/A

DOCUMENT NAME: Hierarquia.SchDoc | SHEET: 1 OF 8


ADDRESS UFCG Laboratório VIRTUS CC Campina Grande, PB - Brasil

PROJECT HAT RPi 4 - Phase Shifter Fotônico | VERSION v1.0

TITLE DAC AD5391 | SIZE A3 | SCALE N/A

DOCUMENT NAME: Main.SchDoc | SHEET: 2 8


ADDRE S S UF C G Laborat ó rio VIR TUS CC Campina Grande, P B -B rasil

PROJE C T HAT RPi 4 - Phase Shifter Fot ônico | V ERSIO N
TIT L E AmpOps de Pot | v1.0 SHEET: SIZ E | SCAL E N/A

ência DOCUM ENT NAM : | A3 Amp_op1.SchDoc 3

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

PROJE C T HAT RPi 4 - Phase Shifter Fot ônico | V ERSIO N
TIT L E Font e | v1.0 SHEET: SIZ E A3 | SCAL E N/A

fonte.S c h o c

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

ência | A3 Amp_op2.SchDoc 5

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

ência | A3 Amp_op3.SchDoc 6

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

ência | A3 Amp_op4.SchDoc 7

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

PROJE C T HAT RPi 4 - Phase Shifter Fot ônico | V ERSIO N
TIT L E Filtros | v1.0 SHEET: SIZ E A3 | SCAL E N/A

Capacitores. c h o c

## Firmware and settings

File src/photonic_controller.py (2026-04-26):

import spidev
import time
import struct
import threading
import RPi.GPIO as GPIO

class PhotonicControllerHAT:
    """
    Abstração sistêmica da Placa HAT responsável por acionar matrizes fotônicas.
    Interfaces lógicas gerenciam a carga SPI de 24-bit no DAC AD5391 (Canais 0-15)
    e a captura contínua nos chips ADC para instrumentação do sensoriamento.
    """

    # --- Constantes do Hardware Físico ---
    PIN_CLR = 22       # Pino Clear assíncrono (Derrubada Global)
    PIN_LDAC = 27      # Pino de Transferência/Atualização Síncrona do Latch 
    PIN_RESET = 17     # Pino para HW Reset das condições de falha

    MAX_VOLTAGE = 3.3  # Limite máximo de excursão dos buffers RRIO (V)
    MAX_MA_PER_CH = 45.5 # Fronteira nominal de potência na fotônica (mA)
    
    # Derivados da calibração do INA180A2 (Gain = 50 V/V) e Shunt R=1 Ohm
    INA_GAIN = 50.0 
    R_SHUNT = 1.0

    def __init__(self):
        """
        Inicializador construtivo dos GPIOs da placa HAT e 
        das instâncias virtuais do barramento do Kernel Linux (spidev).
        """
        self._setup_gpio_state()
        self._init_spi_interfaces()
        self._perform_hardware_reset()

        # Flags de contenção térmica
        self.system_running = True

        # Inicia a Thread Assíncrona dedicada exclusivamente para 
        # proteção contra sobrecorrentes (Supervisório Daemonizado).
        self.watcher_thread = threading.Thread(target=self._current_watchdog_loop, daemon=True)
        self.watcher_thread.start()

    def _setup_gpio_state(self):
        """ Eleva os pinos lógicos auxiliares e desativa funções disruptivas """
        GPIO.setmode(GPIO.BCM)
        GPIO.setwarnings(False)
        # Níveis altos inativam as ações destrutivas (Active Low)
        GPIO.setup(self.PIN_CLR, GPIO.OUT, initial=GPIO.HIGH)
        GPIO.setup(self.PIN_LDAC, GPIO.OUT, initial=GPIO.HIGH)
        GPIO.setup(self.PIN_RESET, GPIO.OUT, initial=GPIO.HIGH)

    def _init_spi_interfaces(self):
        """ 
        Configura o Barramento SPI principal (SPI0) direcionado ao DAC de forma 
        dedicada, garantindo taxas ultra-rápidas de comutação dos registros. 
        O Barramento auxiliar (SPI1) rastreia a aquisição diferencial (ADC).
        """
        self.spi_dac = spidev.SpiDev()
        self.spi_dac.open(0, 0) # SPI0, CE0
        # Tolerância a 20MHz do protocolo AD5391; CPOL=0 CPHA=1 (Mode 1 ou 2)
        self.spi_dac.max_speed_hz = 15000000 
        self.spi_dac.mode = 0b01 # Clock Phase Mode compatível

        # ADC via SPI secundário. Modulação suave para amostragens em kSPS.
        self.spi_adc = spidev.SpiDev()
        self.spi_adc.open(1, 0) # SPI1, CE0
        self.spi_adc.max_speed_hz = 1200000

    def _perform_hardware_reset(self):
        """ Gatilha o Pino Físico cravando o AD5391 em modo nominal nulo. """
        GPIO.output(self.PIN_RESET, GPIO.LOW)
        time.sleep(0.02) # Atrasa no pulso HW (Setup Time)
        GPIO.output(self.PIN_RESET, GPIO.HIGH)
        time.sleep(0.01)

    def trigger_sync_update(self):
        """
        Comuta as tensões do Registrador de Background para a porta física 
        simultaneamente, eliminando transientes de desbalanceamento na fotônica.
        """
        GPIO.output(self.PIN_LDAC, GPIO.LOW)
        time.sleep(0.001)
        GPIO.output(self.PIN_LDAC, GPIO.HIGH)

    def trigger_emergency_clamp(self):
        """ Zera o potencial de tensão de forma bruta e instantânea nas linhas. """
        print("\n[!] ATENÇÃO: OVERRIDE LÓGICO DETECTADO. LIMPANDO MATRIZ ANALÓGICA.")
        GPIO.output(self.PIN_CLR, GPIO.LOW)
        time.sleep(0.005)
        GPIO.output(self.PIN_CLR, GPIO.HIGH)

    def set_voltage(self, channel: int, voltage: float):
        """
        Mapeia a solicitação decimal escalar de Tensão em Volts para um 
        quadro binário contínuo de 24-bits interpretado pelo CI AD5391.
        """
        if not (0 <= channel <= 15):
            raise ValueError("Falha no Mapeamento do Canal (0 a 15).")

        voltage = max(0.0, min(self.MAX_VOLTAGE, voltage))

        # A transferência nominal VOUT baseia-se num espectro VREF escalonado.
        # Considerando a referência local em 1.65V e buffer nativo de ganho x2.
        # Quantização absoluta: 12-bits = 4096 passos
        code = int((voltage / self.MAX_VOLTAGE) * 4095)
        
        # Constrói o Frame de 24 Bits (Byte 1)
        # Seguido pelas flags (Byte 2)
        # E remanescente (Byte 3)
        
        byte_1 = channel & 0x0F
        
        # Inserção das flags 1,1 (binário 11000000 = 0xC0) combinada a metade do DAC
        reg_flags = 0xC0 
        data_upper_6 = (code >> 6) & 0x3F
        byte_2 = reg_flags | data_upper_6
        
        data_lower_6 = (code & 0x3F) << 2
        byte_3 = data_lower_6

        frame = [byte_1, byte_2, byte_3]
        
        # Envia de forma atômica para o barramento SPI local
        self.spi_dac.xfer3(frame)

    def get_measured_current_ma(self, channel: int) -> float:
        """
        Lê e decodifica a tensão transladada proveniente dos Chips INA180A2.
        Suposição de um MCP3008 de 10 Bits em malha fechada.
        """
        # Comando Singe-Ended pro MCP3008 via SPI
        comando_spi = 0x80 | (channel << 4)
        resposta = self.spi_adc.xfer2([1, comando_spi, 0])
        raw_adc = ((resposta & 0x03) << 8) | resposta

        v_adc_lido = (raw_adc / 1023.0) * self.MAX_VOLTAGE
        
        # A corrente base provém da divisão da leitura pelo fator dos Buffers.
        corrente_amperes = v_adc_lido / (self.INA_GAIN * self.R_SHUNT)
        return corrente_amperes * 1000.0 # Transposição escalar para miliamperes

    def _current_watchdog_loop(self):
        """
        Fio de execução autônomo. Rastreia exaustivamente os canais e
        imputa bloqueio caso as densidades extrapolem a banda estipulada.
        """
        while self.system_running:
            for ch in range(16):
                corrente_ma = self.get_measured_current_ma(ch)
                if corrente_ma > self.MAX_MA_PER_CH:
                    print(f"\n!!! SOBRECARGA DETECTADA! CANAL {ch} LEU {corrente_ma:.1f} mA!!!")
                    self.trigger_emergency_clamp()
                    # Bloqueio protetivo para forçar o decaimento termodinâmico
                    time.sleep(2.0)
            time.sleep(0.01)

    def terminate_operations(self):
        """ Desmontagem dos artefatos Python e limpeza dos pinos """
        self.system_running = False
        self.trigger_emergency_clamp()
        self.spi_dac.close()
        self.spi_adc.close()
        GPIO.cleanup()


if __name__ == "__main__":
    controller = PhotonicControllerHAT()
    print("==============================================")
    print("   Módulo Interativo de Controle HAT INICIADO ")
    print("==============================================")
    
    try:
        while True:
            print("\n--- Configuração de Saída Analógica ---")
            canal_str = input("Digite o número do CANAL (0 a 15) ou 'sair' para encerrar: ")
            
            # Condição de saída do programa
            if canal_str.strip().lower() == 'sair':
                break
            
            # Validação do Canal
            try:
                canal = int(canal_str)
                if not (0 <= canal <= 15):
                    print("Erro: O canal deve estar estritamente entre 0 e 15.")
                    continue
            except ValueError:
                print("Erro: Entrada inválida. Digite um número inteiro para o canal.")
                continue
                
            # Validação da Tensão
            tensao_str = input(f"Digite a TENSÃO desejada para o Canal {canal} (0.0 a 3.3 V): ")
            try:
                tensao = float(tensao_str.replace(',', '.'))
                if not (0.0 <= tensao <= 3.3):
                    print("Erro: A tensão ultrapassa os limites seguros (0.0 a 3.3 V).")
                    continue
            except ValueError:
                print("Erro: Entrada inválida. Digite um número decimal para a tensão.")
                continue
            
            # Grava a tensão na memória do DAC (ainda não altera a saída física)
            controller.set_voltage(canal, tensao)
            print(f"-> Tensão de {tensao:.2f}V registrada na memória do Canal {canal}.")
            
            # O usuário escolhe quando acionar o pino de sincronização (LDAC)
            aplicar = input("Deseja aplicar fisicamente as tensões pendentes nos canais agora? (s/n): ")
            
            if aplicar.strip().lower() == 's':
                controller.trigger_sync_update()
                print(">>> Atualização Síncrona Disparada! As tensões estão ativas nas saídas.")
                
                # Leitura instantânea por telemetria para verificação rápida
                time.sleep(0.1) # Aguarda um breve momento para estabilização térmica e elétrica
                corrente_atual = controller.get_measured_current_ma(canal)
                print(f" >> Diagnóstico: O Canal {canal} está drenando aproximadamente {corrente_atual:.2f} mA.")
            else:
                print(">>> As tensões permanecem pendentes na memória. Configure outros canais se desejar.")

    except KeyboardInterrupt:
        print("\nSinal interativo (CTRL+C) processado pelo usuário.")
    finally:
        print("Encerrando operações e zerando as saídas de tensão para segurança...")
        controller.terminate_operations()
        print("Sistema desligado com sucesso.")
